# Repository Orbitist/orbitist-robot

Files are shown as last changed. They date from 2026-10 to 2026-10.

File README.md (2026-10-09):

# Orbitist Robot

An open-source, general-purpose farm robot that farmers can build from off-the-shelf, salvaged, and used parts, plus 3D-printed pieces and lightly fabricated metal.

**First job:** autonomously mowing the lawns on our farm (prototype built winter 2026–27).
**Later jobs:** towing small loads (mulch), carrying sensors, and a light arm for weeding and pruning.

## Status

Design, analysis, and simulation, done before buying parts. Start with:
- **[Platform v1 design](docs/design/platform-v1.md)**: what we're building and why
- **[Confidence plan](docs/design/confidence-plan.md)**: what's verified, what isn't, and the tests to run before the main purchase
- **[Simulation](software/sim/README.md)**: plan mowing and run the autopilot in software
- **[Build tutorial](docs/build/README.md)**: step-by-step assembly with purchase links, one step at a time
- **[Form factors from first principles](docs/design/form-factor-exploration.md)**: swarms, gantries, cable robots, animals, solar: what shape of robot a polyculture farm needs, and what it changes for v1

## Repository layout

```
docs/
  concept/     Original concept work (Sept 2026 vineyard robot design report)
  design/      Current design documents (platform-v1.md)
  decisions/   Decision log: what we chose and why
  guides/      How-to guides (RTK base station setup)
  build/       Step-by-step build tutorial with purchase links and a measurements record
hardware/
  bom/         Bills of materials (CSV) and ordering plan
  cad/         Parametric CAD model, renders, cutting DXFs, strength check
  electrical/  Power distribution, e-stop safety chain, wiring, commissioning tests
software/
  ardupilot/       Autopilot parameters + blade-interlock Lua script
  sim/             Coverage planner + ArduPilot SITL acceptance tests
  base-station/    RTK base (u-blox ZED-F9P) configuration script
  estop_receiver/  Fail-safe wireless e-stop firmware (Arduino)
```

## License

Hardware: [CERN-OHL-W-2.0](LICENSES/CERN-OHL-W-2.0.txt) · Software: [Apache-2.0](LICENSES/Apache-2.0.txt) · Docs: [CC BY-SA 4.0](LICENSES/CC-BY-SA-4.0.txt). See [LICENSE.md](LICENSE.md) for what applies where.

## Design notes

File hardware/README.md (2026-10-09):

# Hardware

| Folder | Contents |
|---|---|
| `bom/` | Bills of materials as CSV (one file per platform version) and the [ordering plan](bom/ordering-plan.md) (what to buy when). Prices are rough estimates as of Oct 2026. |
| `cad/` | [Parametric build123d model](cad/README.md) of the frame: STEP, renders, DXF plates, cut list, mass/CG report |
| `electrical/` | [Power distribution, e-stop safety chain, signal wiring, fuses, commissioning tests](electrical/README.md) |

Design rationale lives in [`docs/design/platform-v1.md`](../docs/design/platform-v1.md).

**v1 BOM rough totals (new parts):**
- Core mowing robot (razor deck + solar roof) + RTK base station (phases 0–1c, without optional GPS-yaw): **~$3,400**
- Everything listed, including GPS-yaw, hitch, and phase-2 compute and sensors: **~$4,040**

Analyses that regenerate from the CAD parameters: [strength](cad/exports/strength-report.md), [drive & energy](cad/exports/drive-energy-report.md), [layout & clearances](cad/exports/report.md).

The RTK base (~$280) is a one-time farm asset shared by every future robot. There is no charging dock: the solar roof keeps the robot charged (D28). The biggest savings come from salvaged parts: a hoverboard board instead of VESCs (−$135), a used e-bike pack, and used rigid solar panels.

Licensed under [CERN-OHL-W-2.0](../LICENSES/CERN-OHL-W-2.0.txt).

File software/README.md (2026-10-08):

# Software

| Folder | Contents |
|---|---|
| [`ardupilot/`](ardupilot/README.md) | Rover 4.6 parameter files and the blade-interlock Lua script that run on the flight controller |
| [`sim/`](sim/README.md) | Coverage planner (lawn → missions + fences) and ArduPilot SITL acceptance tests |
| [`base-station/`](base-station/README.md) | RTK base station configuration (u-blox ZED-F9P) |
| [`estop_receiver/`](estop_receiver/README.md) | Fail-safe wireless e-stop firmware (Arduino Nano) |
| `ros2/` | *(phase 2)* Companion-computer workspace on the Pi 5: camera, obstacle detection, dock AprilTag |

Architecture: [`docs/design/platform-v1.md` §6.3](../docs/design/platform-v1.md#63-navigation-and-control).

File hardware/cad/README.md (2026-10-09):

# CAD: platform v1 frame (code-based, build123d)

The robot is modelled in Python with [build123d](https://github.com/gumyr/build123d) (OpenCascade kernel). `params.py` holds every dimension in one place. `build.py` regenerates the STEP files, renders, flat-plate DXFs, cut list, and an engineering report.

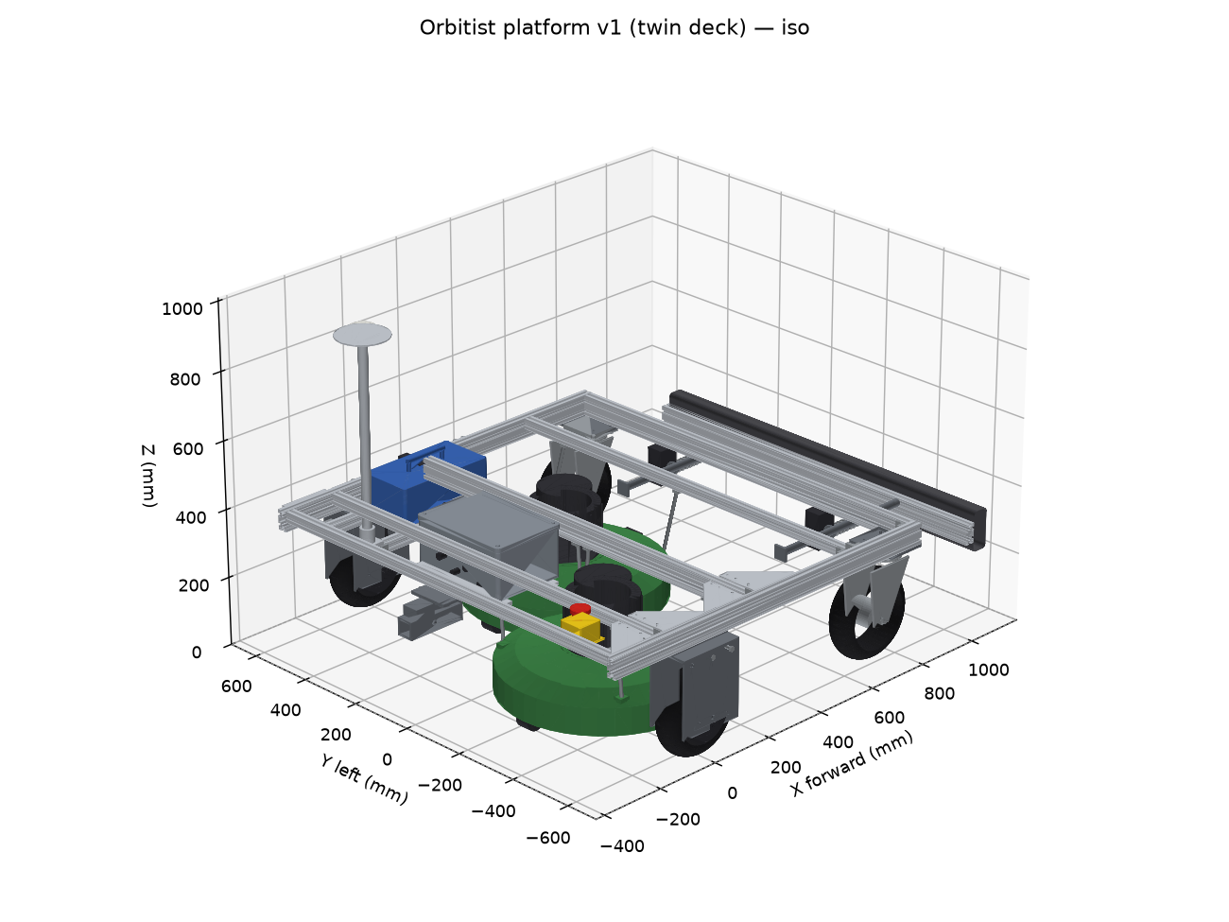
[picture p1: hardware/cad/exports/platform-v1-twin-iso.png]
Twin-deck layout, isometric


## Files

| File | What it is |
|---|---|
| `params.py` | **All dimensions and masses.** Values marked `ESTIMATE` are typical sizes for parts we haven't bought; replace them with measurements. |
| `model.py` | Assembles the parts and re-exports the helpers the analyses use |
| `parts/common.py` | T-slot extrusion profile (30-series, slot 8), hex bolts and nuts, rods, colours by material |
| `parts/plates.py` | **2D outlines of every cut plate** (fork side plate, torque arm, gusset, caster plate). The 3D model extrudes them and the DXFs are exported from them, so they can't drift apart. |
| `parts/frame.py` | Rails and members with real T-slot sections, cast corner brackets, top-face gussets, battery support rails, all bolts |
| `parts/drive.py` | Hub motors (treaded tire, rim, can, side covers, flatted axle), bolt-on forks with saddle tabs, torque arms, axle nuts, motor cables |
| `parts/casters.py` | Plate-mount swivel casters (top plate with bolt pattern, raceway, yoke legs, axle, hub) on the steel corner plates |
| `parts/deck.py` | Ryobi-class deck shells (revolved pan with skirt and rib), blades with lift wings, finned motor housings, anti-scalp rollers, four threaded-rod hangers per deck with drop-in slot blocks |
| `parts/razor_deck.py` | Razor-disc deck: plate cut back to the caster swivel circle, skirt, four disc motors, discs from `razor-disc.dxf`, pivoting blades, rollers, hangers |
| `parts/roof.py` | Solar roof: posts, rails, panels, MPPT, GNSS antenna stub and e-stop on the rear rail |
| `parts/payload.py` | Battery with handle and connector on a lipped tray with strap, IP65 box with lid, glands and mounting feet, GNSS mast with ground plane and antenna, e-stop, 2" hitch receiver with pin, sprung bumper with guide blocks, trip collars and roller microswitches |
| `build.py` | Exports everything to `exports/` and runs clearance checks |
| `strength.py` | Hand-calculation strength check → `exports/strength-report.md` |
| `drive_energy.py` | Hub-motor operating points, heating, and the daily energy budget → `exports/drive-energy-report.md` |
| `exports/platform-v1-{single,twin}.step` | Full assembly. Open in Onshape (*Import*), FreeCAD, Fusion, or any STEP viewer. |
| `exports/*-{iso,top,side,front}.png` | Quick-look renders |
| `exports/platform-v1-detail-*.png` | Close-ups: drive module, front corner (caster + bumper), Ryobi deck hangers, rear, razor deck from below, solar roof |
| `exports/*.dxf` | Flat patterns: drive-fork side plate (6 mm steel ×4), torque arm (5 mm steel ×4), frame gusset (×8), caster plate (×2), razor disc (3 mm aluminium ×4) |
| `exports/strength-report.md` | Load cases, stresses and safety factors for forks, joints, and frame members |
| `exports/cut-list.md` | Extrusion lengths to cut |
| `exports/report.md` | Envelope, mass, CG, axle loads, tongue-weight limit, clearance checks |

## Configurations

- **razor** (v1 baseline, D27/D28): four Ø280 mm razor-blade discs on a 3 mm plate with an HDPE skirt, 1.06 m symmetric cut, plus the solar roof (posts, 30x30 roof frame, two panels, MPPT) carrying the GNSS antenna and e-stop.
- **single**: one Ryobi deck in the twin layout's **rear-right** slot (weekly-capable cutting, needs the dock), no roof.
- **twin**: v1.5, two decks **staggered** (rear-right, front-left) so their cuts overlap by 50 mm. Two decks side by side would leave an uncut strip, because the deck housing is wider than the blade. The frame is the same for both.

## Regenerate

```bash
cd hardware/cad
uv venv --python 3.12 .venv
uv pip install --python .venv/bin/python -r requirements.txt
.venv/bin/python build.py
.venv/bin/python strength.py
.venv/bin/python drive_energy.py
```

`build.py --details` regenerates only the close-up renders (fast) while adjusting views. A full build takes about a minute, most of it in clearance checks and renders.

Commit the regenerated `exports/` together with the parameter change, so the repo stays readable without Python.

## What this model is (and isn't)

- **Detailed layout model (v1).** Every structural part is modelled the way it would be built: real T-slot sections, bolted joints with brackets and gussets, plates from the same outlines as the DXFs, fasteners at every joint. Purchased parts (hub motors, casters, the Ryobi deck, battery, enclosure) are modelled from typical catalog dimensions and will be replaced by measured ones (below). The STEP has ~350 solids and opens in Onshape or FreeCAD.
- **Clearance checks** run on the full model: decks (shell, blade, motor, rollers) against the frame, brackets, forks, wheels and casters; caster swivel sweep against the decks and bumper parts; hangers against everything they shouldn't touch; payload against the deck motors; bumper travel against the caster sweep. The detailed model caught one clash the block model missed: the right hub motor's cable exit ran into deck 1's skirt, which is only ~18 mm from the axle end. The cable now turns up at the axle.
- **Strength:** `strength.py` hand-checks the forks, joints, and members ([report](exports/strength-report.md)). It led to the torque arms, saddle-mounted forks, gussets, and the 30x60 member at x = 215. It's not FEA; the frame is simple enough that beam and plate checks catch the real risks.
- **Not modelled yet:** wiring beyond the motor cables, the belly pan, the VESCs inside the enclosure, the deck's blade-brake and switch wiring, and the charging-dock contacts (phase 2).

## Measure when parts arrive, then update `params.py`

1. Hub motor: tire OD and width, **dropout spacing** (shoulder to shoulder), **axle flats width**, axle length past each shoulder
2. Caster: wheel OD and width, trail, overall height from ground to the mounting plate
3. Ryobi deck (handle and wheels removed): housing outline, motor housing diameter and height, cutting height range, mass
4. Battery and enclosure dimensions

Licensed under [CERN-OHL-W-2.0](../../LICENSES/CERN-OHL-W-2.0.txt); the code in this folder is also available under [Apache-2.0](../../LICENSES/Apache-2.0.txt).

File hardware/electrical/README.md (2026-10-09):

# Electrical design: platform v1

*Status: design for review before purchasing. Part numbers are examples; any part meeting the listed ratings works.*

The design follows four rules:

1. **Every fault fails toward "stopped".** The e-stop loop is normally-closed and in series, and every element in it must be actively *held* closed. A broken wire, a dead radio, or a crashed computer all stop the robot.
2. **Stop, then disconnect.** Cutting power to the motor controllers instantly makes hub motors *coast*. On grass at 1 m/s that's ~0.5 m of rolling, so the e-stop first commands **active braking** and then removes drive power about 1 s later. This is a "Category 1" stop in machine-safety terms.
3. **The safety chain doesn't depend on software.** ArduPilot also disarms on an e-stop, but the hardware path brakes and disconnects even if the autopilot is frozen or commanding full speed.
4. **The blade has its own cut-off**, which drops instantly with the e-stop loop no matter what the autopilot commands.

---

## 1. Power distribution

```mermaid
flowchart LR
    BAT["36 V battery<br/>10S Li-ion / 12S LFP, 20 Ah<br/>BMS ≥ 30 A"] --> F1["F1 main fuse 40 A<br/>(58 V DC rated, MRBF)"]
    F1 --> SW1["SW1 battery disconnect<br/>(≥ 48 V DC rated)"]
    SW1 --> PM["Power module<br/>V + I sense → autopilot"]
    PM --> K1["K1 main contactor<br/>12 V coil, ≥ 60 V DC, ≥ 50 A"]
    PM --> K2R["K2 precharge relay + R1 47 Ω 10 W<br/>(in parallel with K1)"]
    K1 --> BUS["Motor bus 36 V"]
    K2R --> BUS
    BUS --> F2["F2 25 A"] --> VL["VESC left"] --> ML(("Hub motor L"))
    BUS --> F3["F3 25 A"] --> VR["VESC right"] --> MR(("Hub motor R"))
    PM --> F4["F4 5 A"] --> DC12["DC-DC 36→12 V 10 A"]
    PM --> F8["F8 2 A"] --> DC5["DC-DC 36→5 V 5 A"]
    PM -.->|5.2 V| FC["Flight controller"]
    DC12 --> R12["12 V rail (always on):<br/>e-stop loop, contactor coil, timers,<br/>payload, lights"]
    DC5 --> R5["5 V rail (always on):<br/>e-stop receiver, RTCM radio,<br/>relay modules, Pi (phase 2: own 5 V 5 A)"]
```

- **Electronics stay powered during an e-stop** (they're fed before K1), so the autopilot keeps logging, GPS keeps its fix, and the robot can report what happened. SW1 is the only thing that turns everything off.
- **Precharge:** VESCs have large input capacitors. Closing K1 onto empty capacitors arcs and eventually welds the contactor. K2 + R1 charge the capacitors first (τ ≈ 47 Ω × ~3000 µF ≈ 0.15 s), and K1 closes 1.5 s later.
- **Blade power (razor deck, D27):** the four disc drivers take 36 V from the motor bus through F6 (15 A) and are switched together by K5's contacts on their enable lines, so one relay drops all four discs. (The earlier Ryobi-deck plan, with the deck on its own battery, is kept in §6 for the `twin` configuration.)
- **Solar (D28):** the MPPT charge controller's output connects to the battery side of F1 through its own 15 A fuse, so it charges whether or not SW1 is on; its panel input comes down from the roof through a gland.

## 2. Safety chain (e-stop loop)

```mermaid
flowchart LR
    V12["+12 V"] --> F5["F5 2 A"] --> S1["S1 mushroom<br/>e-stop (NC)"] --> S2["S2 bumper<br/>switch L (NC)"] --> S3["S3 bumper<br/>switch R (NC)"] --> K3["K3 wireless e-stop<br/>relay (held closed<br/>by receiver)"] --> SAFE(["SAFE 12 V"])
    SAFE --> K4["K4 signal relay (DPDT)<br/>passes VESC L/R PWM"]
    SAFE --> K2C["K2 precharge relay coil"]
    SAFE --> T1["T1 ON-delay 1.5 s"] --> T2["T2 OFF-delay 1.0 s<br/>(powered from always-on 12 V)"] --> K1C["K1 contactor coil"]
    SAFE --> K5C["K5 blade relay coil<br/>(switched by autopilot)"]
    SAFE --> OPTO["Optocoupler → autopilot GPIO<br/>'ESTOP_OK'"]
```

**What happens when the loop opens** (button pressed, bumper hit, transmitter off or out of range, wire broken):

| Time | Event | Independent of software? |
|---|---|---|
| 0 ms | **Blade relay K5 drops**, cutting the blade start circuit; the mower's own brake stops the blade (< 3 s) | ✅ |
| 0 ms | **K4 opens the PWM signal lines** to both VESCs | ✅ |
| ~100 ms | VESCs detect signal timeout and apply **timeout brake current**, braking the robot to a stop | ✅ (VESC firmware setting) |
| ~0–100 ms | Autopilot sees ESTOP_OK go low, disarms, sets the blade relay output off, logs the event | software, belt-and-braces |
| 1.0 s | T2 releases → **K1 opens, removing drive power** (and K2 has already dropped) | ✅ |

**What happens when the loop closes again:**
1. K2 precharges the VESC capacitors.
2. After 1.5 s, T1 → T2 → K1 closes the main contactor.
3. K4 reconnects the PWM lines, but the **robot does not move**: ArduPilot is disarmed and outputs no pulses (`MOT_SAFE_DISARM = 1`), so the VESCs keep braking. Moving again needs a deliberate re-arm on the transmitter's arm switch, and the blade needs a mission command.

**Stopping distance** (bumper design: see [`strength-report.md`](../cad/exports/strength-report.md#bumper-stopping-distance)): braking at ~3 m/s² after ~0.12 s of latency. That's why **v1 mows at 0.6 m/s**.

## 3. Signal wiring

```mermaid
flowchart LR
    subgraph FC["Flight controller (Pixhawk 6C class)"]
      S1o["MAIN/AUX 1"]
      S3o["MAIN/AUX 3"]
      RLY["AUX n (relay out)"]
      GPIO["AUX m (GPIO in)"]
      GPS1["GPS1"]
      TEL1["TELEM1"]
      RCIN["RC IN / serial"]
    end
    S1o --> K4a["K4 contact A"] --> VLs["VESC L PPM in"]
    S3o --> K4b["K4 contact B"] --> VRs["VESC R PPM in"]
    RLY --> K5M["Opto relay module IN<br/>(K5 coil from SAFE 12 V)"] --> RYOBI["Ryobi start circuit<br/>(see §6)"]
    OPTO2["Optocoupler (SAFE 12 V)"] --> GPIO
    GPS1 --- F9P["Rover ZED-F9P (UART1)"]
    RADIO["RTCM radio (from base)"] --> F9P2["Rover ZED-F9P UART2"]
    TEL1 --- SIK["Telemetry radio ↔ laptop"]
    RCIN --- ELRS1["ELRS receiver #1<br/>(driving, arm switch)"]
    ELRS2["ELRS PWM receiver #2"] --> NANO["E-stop receiver<br/>(software/estop_receiver)"] --> K3c["K3 relay (in e-stop loop)"]
```

- With K4 open, each VESC's PPM input must be **pulled to ground** (10 kΩ at the VESC end) so it sees "no signal" rather than noise.
- Run PWM and sensor wires as twisted pairs with their ground, away from motor phase wires.
- **One ground point:** the battery negative at the power module. Signal grounds follow their signals. Don't create a second path through the frame.

## 4. Fuses and wire

All fuses and fuse holders on the 36 V side must be **rated ≥ 58 V DC**. Ordinary automotive blade fuses are rated 32 V and may not interrupt a 42 V DC fault.

| Circuit | Fuse | Wire (silicone, chassis wiring) | Notes |
|---|---|---|---|
| Battery → SW1 → power module → K1 | F1 40 A (MRBF or Class T at the battery) | 10 AWG | As short as possible; F1 within 15 cm of the battery |
| Motor bus → each VESC | F2/F3 25 A (58 V ATO/MINI) | 12 AWG | Battery current limit per VESC is set to 14 A (§5) |
| Precharge K2 + R1 | inherent (R1 limits to < 1 A) | 18 AWG | R1: 47 Ω, 10 W, wirewound |
| DC-DC 12 V input | F4 5 A | 16–18 AWG | |
| DC-DC 5 V input | F8 2 A | 18 AWG | |
| E-stop loop (12 V) | F5 2 A | 20 AWG | Contactor coil ~0.3–0.5 A |
| Signals | — | 22–26 AWG twisted | |

Crimp, don't solder, anything that vibrates (use ferrules on screw terminals) and strain-relieve at the enclosure glands.

## 5. Settings that are part of the safety design

These live in configuration rather than wiring, but the design depends on them. Record them in `software/ardupilot/` and in the VESC config backups.

**VESC (each controller, VESC Tool):**

| Setting | Value | Why |
|---|---|---|
| Sensor mode | Hall sensors (FOC) | Smooth low-speed torque (design doc §5) |
| Battery current max | 14 A | Two VESCs stay under the 30 A BMS limit |
| Motor current max | ~50 A | ≈ 28 N·m with a typical torque constant of ~0.57 N·m/A. Keeps torque under the 40 N·m the forks and torque arms were checked for. Re-compute from the measured motor constant after VESC motor detection. |
| Motor current max brake | 30 A | Braking torque |
| App: PPM, **control type "PID speed"**, max ERPM ≈ 2 m/s wheel speed | — | Throttle maps linearly to wheel speed, so 0.6 m/s is 30 % throttle instead of ~7 % duty. Gives finer low-speed control and an easier ArduPilot speed tune (`CRUISE_THROTTLE 30`). |
| App: PPM, **timeout 100 ms**, **timeout brake current 20 A** | — | This is what stops the robot when K4 cuts the signal or the autopilot dies |
| Battery cutoff start/end | Set for the pack chemistry | Protects the battery before the BMS has to |

**ArduPilot (Rover):** skid-steer outputs `SERVO1_FUNCTION = 73`, `SERVO3_FUNCTION = 74`; `MOT_SAFE_DISARM = 1` (no pulses when disarmed); arm with a **switch**, never stick-arming; RC and GCS failsafe → Hold; battery failsafe from the power module; geofence → Hold. A Lua script watches the ESTOP_OK input and disarms. The full parameter file comes with the autopilot setup.

## 6. Open item: Ryobi blade control (bench test)

How the robot switches the blade depends on the specific mower:

1. Open the handle wiring. Find the **bail switch** (the lever you hold) and the **start button**.
2. With a multimeter, measure the current through each while the mower runs (on a bench, blade removed or safely guarded).
   - **Low current (< 1 A):** these are signal inputs to the mower's brushless controller. K5 can be a small relay replacing the bail switch, plus a second relay or the same relay to "press" start (a ~0.5 s pulse from the autopilot, held by the bail relay).
   - **High current:** the bail switch carries motor power. K5 must be a DC contactor rated ≥ 60 V DC at the motor current.
3. Confirm that opening the bail circuit stops the blade within 3 s (blade brake).

Record the results in this file and update the K5 entry.

## 7. Parts list (electrical)

| Ref | Part | Rating / notes |
|---|---|---|
| F1 | Terminal-mount fuse (Blue Sea MRBF class) + holder | 40 A, 58 V DC |
| SW1 | Battery disconnect switch (Blue Sea m-Series class) | ≥ 48 V DC, ≥ 50 A |
| PM | Analog power module | ≥ 12S input, ≥ 60 A; supplies the flight controller |
| K1 | DC contactor, 12 V coil | ≥ 60 V DC, ≥ 50 A continuous (e.g. Albright SW60 / TE LEV100 class) |
| K2, R1 | 12 V automotive relay + 47 Ω 10 W resistor | Precharge |
| T1 | 12 V on-delay timer relay module | Adjustable, set 1.5 s |
| T2 | 12 V off-delay timer relay module | Trigger input + separate supply, set 1.0 s |
| K3 | 5 V relay module, active-HIGH | Driven by the e-stop receiver |
| K4 | 12 V DPDT signal relay | Gold-flashed contacts for low-level signals |
| K5 | 12 V-coil relay with opto-isolated 3.3 V input | Or a DC contactor; depends on the §6 bench test |
| S1 | 22 mm mushroom e-stop, twist-release, **NC** contact block | Mounted at the rear top, reachable from behind the robot |
| S2, S3 | Roller-lever microswitches, **NC** used | IP67 if available |
| — | Optocoupler module (12 V in → 3.3 V out) | ESTOP_OK to the autopilot |
| — | 2× DC-DC converters | 36→12 V 10 A, 36→5 V 5 A; input ≥ 60 V |
| — | 58 V fuse block + fuses | F2–F8 |
| — | E-stop receiver | Arduino Nano + ELRS PWM receiver ([software/estop_receiver](../../software/estop_receiver/README.md)) |

## 8. Commissioning tests

Do these in order, with the **drive wheels off the ground** and **no blade fitted** until step 6.

1. **Polarity and fuses:** with SW1 off, check every fuse is fitted. Measure the main bus with a meter before the first switch-on, using a current-limited bench supply if possible.
2. **Precharge:** loop closed → bus voltage rises within ~0.5 s → contactor clicks at ~1.5 s with no spark or arc sound.
3. **Each loop element** (S1, S2, S3, transmitter off, RUN switch down, a loop wire unplugged) must each:
   - drop the blade relay immediately,
   - make the wheels brake within ~0.1 s (spin them by hand first: they should resist),
   - open the contactor after ~1 s,
   - make the autopilot log "ESTOP" and disarm.
4. **No restart:** re-close the loop → the robot stays disarmed and the wheels stay braked until re-armed.
5. **Autopilot crash:** while driving with the wheels lifted, unplug the flight controller's power → the VESCs brake within 0.1 s from the signal timeout.
6. **Blade:** with the deck fitted and guarded, run the blade and hit the e-stop → the blade stops in < 3 s.
7. **On the ground:** at 0.6 m/s, push the bumper with a padded board → the robot stops within the bumper's travel.

Repeat steps 3 and 6 at the start of every mowing season and after any wiring change.

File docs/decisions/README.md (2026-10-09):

# Decision log

A short record of design decisions, so future contributors can see *why* things are the way they are. Add a row when a decision is made or revisited. Write a longer note only when a row isn't enough.

| # | Date | Decision | Status | Rationale / link |
|---|---|---|---|---|
| D1 | 2026-10-08 | Build **one robot first**; peer-to-peer docking becomes a later research track | Proposed | Mowing doesn't need a pair; the latch was the top risk. [platform-v1 §2](../design/platform-v1.md#2-what-changes-from-the-vineyard-concept-and-why) |
| D2 | 2026-10-08 | **Zero-turn layout** (2 rear hub motors + 2 front casters) for v1; frame accepts swappable drive modules (wheelchair, 4WD) | Proposed | Turf-friendly pivot turns; proven mower geometry. [§3](../design/platform-v1.md#3-chassis-options-considered) |
| D3 | 2026-10-08 | **ArduPilot Rover** on a flight controller for low-level control and GPS navigation; Pi 5 + ROS 2 added as a companion in phase 2 | Proposed | Mature skid-steer, RTK, missions, failsafes; existing community mower builds. [§6.3](../design/platform-v1.md#63-navigation-and-control) |
| D4 | 2026-10-08 | **RTK GNSS (u-blox ZED-F9P) in phase 1** | Proposed | Coverage mowing needs cm-level repeatability |
| D5 | 2026-10-08 | **VESC-class FOC controllers** by default; hoverboard + EFeru FOC as budget option | Proposed | Direct RC-PWM/CAN from ArduPilot; Hall-sensored low-speed torque |
| D6 | 2026-10-08 | **Mower is a belly-mount module**; v1 uses a salvaged 40 V-max cordless mower deck on its own battery | Proposed | Includes blade brake and height adjust; isolates blade power. [§6.2](../design/platform-v1.md#62-mower-module) |
| D7 | 2026-10-08 | Haul loads by **towing a cart from a rear hitch** rather than carrying them on deck | Proposed | Cart's wheels carry the load; tongue weight adds traction |
| D8 | 2026-10-08 | Battery swap first, then a **fixed AprilTag charging dock** in phase 2 (replaces peer-to-peer charging for lawn use) | Proposed | Simpler; ArduPilot Dock mode exists |
| D10 | 2026-10-08 | Operating model for ~3 acres: **mow in daily zones from a charging dock**; dock is the first item in phase 2 | Proposed | One 21" deck needs ~12.5 h per full pass at 0.6 m/s. [platform-v1 §5](../design/platform-v1.md#5-back-of-envelope-sizing) |
| D11 | 2026-10-08 | **Own RTK base station** (ZED-F9P, position fixed with NOAA OPUS), 915 MHz radio link to the robot; NTRIP caster later | Proposed | No known correction service nearby; one base serves the whole farm |
| D12 | 2026-10-08 | Mower module from a **second used Ryobi mower** sharing the farm's existing batteries and charger | Proposed | Keeps the daily mower in service; reuses the battery ecosystem. Pending model number. |
| D13 | 2026-10-08 | **Code-based CAD (build123d) in `hardware/cad/` is the source of truth**; Onshape/FreeCAD for viewing STEP exports and quick hand-sketched parts (revised same day; originally Onshape) | Accepted | Parametric, diffable in git, regenerates DXFs/cut list/strength check, editable by Claude. [hardware/cad](../../hardware/cad/README.md) |
| D14 | 2026-10-08 | **Frame built for twin decks from day one** (~1.3–1.4 m wide); v1 runs one centered deck | Proposed | 3+ acres, flat, 8 ft paths; widening later would mean rebuilding the frame. [platform-v1 §4](../design/platform-v1.md#4-v1-layout-top-view) |
| D15 | 2026-10-08 | **Licenses:** CERN-OHL-W-2.0 (hardware), Apache-2.0 (software), CC BY-SA 4.0 (docs) | Accepted | Anyone can build and sell; changes to our hardware design are shared back; third-party modules can stay closed; software matches ROS 2. [LICENSE.md](../../LICENSE.md) |
| D16 | 2026-10-08 | From the strength check: **torque arms required**, **saddle-mounted drive forks**, **gussets** at the drive-adjacent joints, **30x60 cross member at x = 215**, **no towing** until an A-frame drawbar is added | Accepted | [strength-report.md](../../hardware/cad/exports/strength-report.md) |
| D17 | 2026-10-08 | **Plate-mount 10" pneumatic swivel casters** on 8 mm steel corner plates (instead of zero-turn mower casters); frame raised to 320 mm; front cross member 30x60 | Accepted | Bolt-on, no welded spindle housing, cheap and swappable. Upgrade to mower casters if shimmy is a problem. |
| D18 | 2026-10-08 | **Category 1 e-stop** (signal cut → VESC brake → contactor opens after 1 s), hardware-only path; **fail-safe wireless e-stop** via microcontroller watchdog; **v1 mowing speed 0.6 m/s** to stay within bumper stopping distance | Accepted | Hub motors coast if power is cut instantly; the bumper only protects ≤ 0.61 m/s. [electrical](../../hardware/electrical/README.md), [strength-report](../../hardware/cad/exports/strength-report.md#bumper-stopping-distance) |
| D19 | 2026-10-08 | Base position from a **24 h log processed by CSRS-PPP**; configure the F9P with our own script (no u-center, so it works on Mac and Pi) | Accepted | [rtk-base-station guide](../guides/rtk-base-station.md) |
| D20 | 2026-10-08 | **v1 deck in the rear-right slot**, not centred | Accepted | Cuts within ~19 cm of obstacles on the right (vs ~43 cm); planner laps put the deck on the boundary; the twin upgrade only adds a deck |
| D21 | 2026-10-08 | **Simulation gate:** every parameter or Lua change must pass `software/sim/run_sitl.py` before it goes on the robot | Accepted | SITL found eight real problems before hardware ([sim README](../../software/sim/README.md)) |
| D22 | 2026-10-08 | Autopilot settings from SITL: `AVOID_ENABLE 2` (no fence avoidance), `WP_RADIUS 0.2`, 15 cm pass overlap, 0.25 m extra obstacle clearance, **pause on RTK loss** (Lua) | Accepted | Each fixes a failure seen in simulation |
| D23 | 2026-10-08 | Own **coverage planner** (perimeter laps + stripes + visibility-graph routing, fences within 80 points) instead of Mission Planner's grid tool | Accepted | Knows the offset deck, the body width, and obstacle clearance; one mission + fence per zone |
| D24 | 2026-10-08 | **De-risk before buying** (T1 Ryobi blade power, T2 RTK survey, T3 one-motor bench test, T4 caster); **battery choice waits for T1** | Accepted | Blade power and motor heating are the two biggest unknowns ([confidence plan](../design/confidence-plan.md)) |
| D25 | 2026-10-08 | VESC PPM in **PID speed** mode (throttle ∝ wheel speed, ~2 m/s full scale) | Proposed | 0.6 m/s = 30 % throttle instead of ~7 % duty; finer low-speed control |
| D26 | 2026-10-08 | The platform is a *system*: v1 carrier for mass + mowing, a 1-D bed gantry or cable robot for polyculture beds (v2), drone + fixed cameras for sensing, animals for margins | Accepted 2026-10-09 | [form-factor-exploration](../design/form-factor-exploration.md); user confirmed daily mowing, solar, animals and a test plot are all welcome |
| D27 | 2026-10-09 | **v1 cutting system is a razor-disc deck** (4 × Ø280 mm discs with pivoting razor blades, ~10–20 W each) for daily increment cutting, replacing the Ryobi deck as the baseline. The farm's existing Ryobi (and the Swisher) are the catch-up mowers for tall growth and spring. | Accepted | 3–10× less cutting energy; lighter, safer deck; symmetric 1.06 m cut. [drive-energy report](../../hardware/cad/exports/drive-energy-report.md) |
| D28 | 2026-10-09 | **Solar roof** (2 × ~110 W semi-flexible panels on a 30x30 roof frame) with an MPPT charger; **36 V 10–15 Ah pack; no charging dock.** GNSS antenna and e-stop move onto the roof's rear rail. | Accepted | ~500–740 Wh/day supply vs ~250 Wh/day typical need; removes phase 2's hardest item |
| D29 | 2026-10-09 | **Sheep with a virtual fence** are the planned mower for orchard floors and margins; the robot mows open lawns | Proposed | Zero-energy mowing plus fertility; user already considering sheep |
| D30 | 2026-10-09 | **v2 is a 1-D bed gantry or cable robot** on a dedicated test plot, sharing v1's electronics; an arm stays on the long-term roadmap | Proposed | Polyculture beds need place/protect work, not a bigger carrier |
| D31 | 2026-10-09 | **Evaluate a ground-driven reel gang** (3 used push reel mowers, belly-mounted, floating on their own wheels) as an alternative to the razor discs; decide from the T1/T1b field test | Open | Shear cut needs no blade electronics or interlock and is inherently stopped when the robot is; but sticks and stalky weeds jam reels, and the drag loads the drive wheels. [step 1 T1b](../build/step-01-de-risk.md) |
| D9 | 2026-10-08 | Correction: "36 V" means **10S Li-ion or 12S LiFePO4** (concept report said 10S LiFePO4, which is only 32 V) | Accepted | Cell chemistry math |

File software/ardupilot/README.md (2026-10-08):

# ArduPilot configuration

| Path | What |
|---|---|
| `params/orbitist-v1.param` | Baseline Rover 4.6 parameters for the real robot: frame, speeds, arming, failsafes, fence, blade relay, scripting. Values marked TUNE are set during commissioning. |
| `params/sitl-overlay.param` | Simulation-only overrides (loaded by `software/sim`). **Never load on the robot.** |
| `scripts/blade_interlock.lua` | Blade interlock + GPS pause/resume + e-stop disarm. Copy to the flight controller's SD card under `APM/scripts/`. |

## Blade control

Missions don't switch the blade relay directly. They send `MAV_CMD_DO_SEND_SCRIPT_MESSAGE` (id 1, param2 = 1 on / 0 off), and the Lua script turns relay 1 (K5) on only while **all** of these hold:

armed · AUTO mode · GPS fix ≥ `BLD_MIN_FIX` (RTK fixed) · no fence breach · tilt < 25° · e-stop loop OK · blade requested

The script also:
- disarms if the e-stop loop opens (the hardware e-stop acts independently: see `hardware/electrical`);
- pauses the mission (Hold) if the RTK fix is lost for 2 s, and resumes once it's been back for 3 s;
- forces the blade off if the script itself errors.

Its parameters (`BLD_*`) appear after the first boot with the script installed. Set `BLD_ESTOP_SRC = 1` and `BLD_ESTOP_PIN` to the GPIO wired to the ESTOP_OK optocoupler. With the pin unset, the script treats the e-stop as tripped (fail safe).

## Installing on the flight controller

1. Flash ArduPilot **Rover 4.6.x** (the version the simulation uses).
2. Mission Planner → Config → Full Parameter List → **Load from file** → `orbitist-v1.param` → Write → reboot.
3. Copy `scripts/blade_interlock.lua` to the SD card at `APM/scripts/`, reboot, and check for "Blade interlock loaded" in Messages.
4. Commission in the order given in `hardware/electrical/README.md` §8, then tune steering and speed per the [ArduPilot Rover tuning guide](https://ardupilot.org/rover/docs/rover-tuning-process.html).
5. Commit any tuned values back to `orbitist-v1.param`.

Every behaviour above is exercised in simulation by `software/sim/run_sitl.py`.

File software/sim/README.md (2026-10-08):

# Simulation: plan and test mowing before the robot exists

Two tools, both using the robot's real geometry (`hardware/cad/params.py`) and its real autopilot configuration (`software/ardupilot/`):

| Tool | What it does |
|---|---|
| `coverage.py` | **Mowing planner.** Turns a lawn file into ArduPilot missions (one per zone, i.e. one day's job), geofences, a coverage map, and a time estimate. |
| `run_sitl.py` | **Acceptance tests.** Boots ArduPilot Rover 4.6.3 in software-in-the-loop (SITL) with our parameters and the blade-interlock Lua script, flies the planned mission, and injects faults. |

## Setup (once, ~10 min)

```bash
cd software/sim
./setup.sh
```

This creates a Python 3.12 environment and downloads and compiles ArduPilot SITL into `ardupilot/` (git-ignored).

## Plan mowing

```bash
.venv/bin/python coverage.py lawns/sample-farm.json                 # single deck
.venv/bin/python coverage.py lawns/sample-farm.json --config twin   # twin decks
```

Output goes to `plans/<lawn>-<config>/`:
- `<zone>.waypoints`: load in Mission Planner.
- `<zone>.plan`: load in QGroundControl. Includes the fence.
- `<zone>-fence.json`: the fence on its own.
- `<zone>.png`: map of the plan. Red marks area the robot can't reach.
- `report.md`: time and coverage per zone.

**The pattern:** the deck sits on the robot's right, so the robot first runs two laps with the deck facing the boundary: counter-clockwise around the lawn, clockwise around trees and beds. It then mows straight stripes at whichever angle needs the fewest turns. At each stripe end the offset deck makes the robot pivot 180° almost in place.

**Lawn files** (`lawns/*.json`) are in metres east/north of an origin. `sample-farm.json` is an invented ~3-acre layout. Replace it with the real lawns once the RTK rover has walked the boundaries; the planner accepts the same format.

## Run the acceptance tests

```bash
.venv/bin/python run_sitl.py                         # all scenarios, small test plot (~3 min)
.venv/bin/python run_sitl.py mission --lawn lawns/sample-farm.json --zone east --speedup 40
```

| Scenario | Pass criteria |
|---|---|
| `mission` | completes; tracking p95 ≤ 0.15 m while mowing; actual cut ≥ planned − 2 %; blade only on while armed in AUTO |
| `rc_loss` | transmitter lost → Hold and blade off within 2.5 s |
| `estop` | e-stop loop opens → disarmed and blade off within 0.5 s |
| `restart` | e-stop released → stays disarmed and still |
| `gps_loss` | GPS lost → blade off within 1 s, paused within 3 s, < 2 m travelled; resumes when the fix returns |
| `fence` | commanded outside the fence → stays within 1 m of it |

Results: [`results/test-plot.md`](results/test-plot.md). Per-run logs, ArduPilot `.BIN` logs, and track plots go in `runs/` (git-ignored).

## What simulation found (and what changed because of it)

| Found in SITL | Change |
|---|---|
| ArduPilot's **fence avoidance** keeps the robot 2 m (`AVOID_MARGIN`) from the fence, stalling the perimeter laps | `AVOID_ENABLE = 2` (proximity only); the fence still stops the robot on a breach |
| **Corner-cutting** with `WP_RADIUS 0.3` took the robot into the fence around a tree | Laps keep an extra 0.25 m from trees and beds; the fence sits where the body would touch; `WP_RADIUS 0.2` |
| **Waypoints a few cm apart** (stripe-end hops) made the robot pivot back and forth for minutes | Planner merges legs < 0.3 m into one pivot point |
| With ±0.14 m tracking, a 7.5 cm overlap left uncut strips (−5 % coverage) | Overlap 0.15 m (revisit with real tracking) |
| After **losing GPS**, the robot dead-reckoned ~8 m before ArduPilot's failsafe | Lua pauses (Hold) after 2 s without an RTK fix and resumes when it's back |
| A full-size zone's fence (119 points) exceeded ArduPilot's **84-point fence store** | Conservative fence simplification within an 80-point budget; `BRD_SD_FENCE` on hardware |
| Real pivot turns cost ~3 s more each than estimated | Planner time model calibrated (`PIVOT_OVERHEAD_S = 5`) |
| SITL reads "no PWM" as full reverse | SITL-only `MOT_SAFE_DISARM 0` (the real VESCs brake on missing pulses) |

## Limits of this simulation

- **Vehicle dynamics are generic.** ArduPilot's `rover-skid` model is a small, fast hobby rover (4 m/s, very high acceleration), not a 65 kg robot on grass. It validates mission logic, safety behaviour, failsafes, coverage geometry, and the planner, but **not** tuning, traction, or braking distances. Steering tuning (`ATC_*`, `PSC_*`) happens on the real robot; the SITL overlay's tuning is model-specific.
- **GPS is idealised:** RTK fixed everywhere with 2 cm noise. Tree-canopy dropouts are tested only as total GPS loss (`gps_loss`).
- **No grass, no blade load, no battery sag.**

Field tests in phase 1b/1c (see `docs/design/confidence-plan.md`) cover what the simulator can't.

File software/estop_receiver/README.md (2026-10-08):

# Wireless e-stop receiver

A $5 microcontroller that turns a dedicated RC receiver channel into a **fail-safe** wireless e-stop. The relay closes only while a valid "RUN" signal keeps arriving. Transmitter off, out of range, a broken wire, the switch flipped down, or the firmware hanging all open the e-stop loop.

Why not a cheap RC relay switch? Most of them **hold their last state on signal loss**, which is the opposite of fail-safe.

## Hardware

| Part | Notes |
|---|---|
| Arduino Nano or Pro Mini (5 V, ATmega328P) | Flash with the current (Optiboot) bootloader. The old Nano bootloader can reset-loop with the watchdog, which still fails safe (relay off) but won't run. |
| ELRS **PWM** receiver (e.g. RadioMaster ER-series) | Dedicated to the e-stop, bound to the same transmitter. **Failsafe = "No Pulses".** |
| 1-channel relay module, 5 V coil, active-HIGH input | Contacts in series with the NC e-stop loop ([electrical design](../../hardware/electrical/README.md)) |

Wiring: receiver channel signal → **D2**; **D7** → relay module IN; 5 V and GND from the robot's 5 V rail to the Nano, receiver, and relay module.

Map a **2-position switch** on the transmitter to that channel: up (~2000 µs) = RUN, down = STOP.

## Build

```bash
arduino-cli compile --fqbn arduino:avr:nano:cpu=atmega328 software/estop_receiver
arduino-cli upload  --fqbn arduino:avr:nano:cpu=atmega328 -p /dev/cu.usbserial-XXXX software/estop_receiver
```

## Acceptance test (do it before every mowing season, and monthly)

Each test must drop the relay (you'll hear it click and see the LED blink):

1. Flip the RUN switch down → relay drops within 0.1 s.
2. Turn the transmitter off → relay drops (time how long it takes; should be ≤ 1 s).
3. Walk out of range (or shield the transmitter in a metal box) → relay drops.
4. Unplug the receiver signal wire → relay drops.
5. Power-cycle the Nano with the switch in RUN → relay stays off for ~0.2 s, then closes.

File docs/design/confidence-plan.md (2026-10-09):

# Confidence plan: what's verified, what isn't, and how we close the gaps before buying

*Status 2026-10-09 (revised for the razor deck and solar roof, D27/D28). Companion to [platform-v1.md](platform-v1.md). Update the status column as tests complete.*

The aim: spend the big money (motors, battery, frame, electronics ≈ $1,500) only after the riskiest assumptions are measured. Most risks can be retired with **about $350 of parts we need anyway**.

## 1. Where the design stands

| Area | How it was checked | Confidence | Evidence |
|---|---|---|---|
| Layout, clearances, weight distribution | Parametric CAD with automated clearance checks | ✅ High for geometry; masses are estimates | [`report.md`](../../hardware/cad/exports/report.md) |
| Frame and bracket strength | Hand calculations, 2.5 g bumps, side skid, motor torque | ✅ High, given catalog extrusion properties | [`strength-report.md`](../../hardware/cad/exports/strength-report.md) |
| Bumper stopping distance → 0.6 m/s mowing speed | Kinematics with an assumed 3 m/s² braking | 🟡 Medium: braking rate must be measured | strength report §bumper |
| Autopilot configuration, failsafes, blade interlock | **ArduPilot SITL**: 13/13 acceptance checks (mission, RC loss, e-stop, restart, GPS loss, fence) | ✅ High for logic; vehicle dynamics are generic | [`results/test-plot.md`](../../software/sim/results/test-plot.md) |
| Coverage pattern and mowing time | Planner + SITL. Full-size sample zone with the Ryobi deck: mission completed, 97.5 % cut vs 98.0 % planned, 6.13 h vs 6.1 h predicted. Razor deck (1.06 m cut): 13/13 checks on the test plot, 93.7 % cut vs 94.1 % planned; 3 acres ≈ **7.7 h/week** | ✅ High for the sample layout; the real lawns aren't mapped yet | [`results/sample-farm.md`](../../software/sim/results/sample-farm.md), [`plans/`](../../software/sim/plans) |
| Hub motors at mowing speed (45 rpm) | Operating-point model with uncertainty ranges | 🟡 OK in the typical case; **worst case overheats** | [`drive-energy-report.md`](../../hardware/cad/exports/drive-energy-report.md) |
| Daily energy, battery size, solar balance | Energy model from coverage time × power, solar yield from panel rating × sun-hours | 🟡 Razor-disc power (10–20 W each) and panel yield are typical values, not measured; typical day has ~3× solar margin, poor-sun worst case is short by ~140 Wh | drive-energy report §2–3 |
| RTK fix over the actual lawns | Not tested | 🟡 Open sky reported; untested near trees and buildings | — |
| Ryobi deck: mass, size, blade switching | Estimates (17 kg, 580 mm housing) | 🔴 Unknown model and wiring | — |

## 2. What simulation found and fixed

These were caught in software, with nothing bought, broken, or mown wrong. Details are in [software/sim/README.md](../../software/sim/README.md#what-simulation-found-and-what-changed-because-of-it).

1. **Fence avoidance stalls edge mowing.** ArduPilot's 2 m avoidance margin → avoidance limited to proximity sensors.
2. **Corner-cutting into trees.** Extra 0.25 m obstacle clearance; fences at the body-contact line; tighter waypoint radius.
3. **Waypoint hunting.** Stripe-end waypoints 3 cm apart made the robot pivot for minutes → the planner merges legs shorter than 0.3 m.
4. **Uncut strips.** With realistic tracking, the pass overlap needed to grow from 7.5 to 15 cm.
5. **Blind driving after GPS loss.** About 8 m of dead-reckoning → the robot now pauses after 2 s and resumes automatically.
6. **Fence storage limit.** A full zone's fence exceeded ArduPilot's 84 points → the planner now fits fences in 80 points.
7. **A planned route through a tree.** A planner bug, caught by a clearance check → replaced by a visibility-graph router; every leg is now verified ≥ 0.17 m from no-go zones.
8. **Operating time.** About 17 h/week with one deck at 0.6 m/s, 8 h/week with two, which changes the twin-deck priority (below).

## 3. Before buying the main parts: four de-risking tests

In this order. Each feeds a number back into `params.py`, `drive_energy.py`, or `coverage.py`, and the reports regenerate.

| # | Test | Buy | ~$ | Answers | Decides |
|---|---|---|---|---|---|
| **T1** | **One razor disc on the bench and on the lawn.** One brushless disc motor + driver, one disc cut from `razor-disc.dxf` with three razor blades, run from the bench supply at 36 V: measure current while cutting a maintained lawn (push it on a hand frame or the deck plate), and while cutting a week's growth. Time the stop after power-off. Also measure one solar panel's midday output lying flat. | 1 disc motor + driver, blades, 1 panel | 80–150 | **Cutting power per disc** (sets the solar balance), blade stop time, panel yield | Pack size (10 vs 15 Ah), disc count, whether a blade brake is needed |
| **T2** | **RTK on a cart.** Set up the base station (guide), put the rover GPS + flight controller on a wheelbarrow, and walk every lawn edge, tree, and bed. | Wave 1 GNSS kit (needed anyway) | (700–900) | RTK fix availability across the real lawns; the **real lawn file** | Real mowing hours and coverage per zone; where the robot can't mow; dock location |
| **T3** | **One hub motor + one VESC on the bench.** Run VESC motor detection (torque constant, resistance), check the axle flats and dropout spacing, test smooth low-speed Hall FOC at 45 rpm, run **30 minutes at mowing torque** (≈ 4–6 N·m: drag a weighted tire or sled) and measure motor temperature, and test the VESC timeout brake. | 1 hub motor + 1 VESC + current-limited bench supply | 210 + 60 | Whether hub motors run cool at mowing speed; real torque constant; braking rate for the bumper calculation | Buy the second motor, or switch to geared or wheelchair motors; final fork-plate DXF; VESC current limits |
| **T4** | **One caster.** Measure the bolt pattern, height, and swivel offset. | 1 caster (need 2 anyway) | 35 | Caster geometry | Caster plate DXF and frame height |

**Then:** cut the plates and order Wave 2 (frame, second motor and VESC, electrical, battery), with every DXF and the battery choice based on measured parts.

## 4. Risk register

| Risk | Likelihood | Impact | Status | Retire by |
|---|---|---|---|---|
| Razor-disc power higher than assumed on farm turf → solar can't keep up | Medium | Medium | 🔴 Open | **T1**; fallback is a bigger pack and occasional mains charging |
| **Robot fails to keep up** (rain week, breakdown) and razors can't cut the backlog | Certain, sometimes | Low | 🟡 Known | The Ryobi/Swisher catch-up mow is part of the operating model |
| Hub motors overheat at mowing speed | Low–medium | High | 🟡 Open | **T3** (fallback: wheelchair or geared motors; frame accepts swappable drive modules) |
| RTK float/no-fix near buildings and trees | Medium | Medium | 🟡 Open | **T2**; the robot pauses on fix loss (SITL-verified) |
| Path tracking on grass worse than ±10 cm → uncut strips | Medium | Low (one more overlap step) | 🟡 Open | Phase 1b field tuning; overlap is one planner parameter |
| Braking on wet grass < 3 m/s² → bumper speed limit < 0.6 m/s | Medium | Medium | 🟡 Open | T3 brake test, then commissioning step 7 |
| Single deck too slow for 3 acres weekly (≈17 h) | High | Medium | 🟡 Known | Twin decks (≈8 h), already designed in; buy the second used Ryobi early |
| Frame or joint failure | Low | High | ✅ Analysed | Gussets, saddle forks, torque arms; check bolt preload after the first hours |
| Autopilot logic error (blade on outside AUTO, no stop on faults) | Low | High | ✅ SITL 13/13 | Re-run `run_sitl.py` after every parameter or script change |
| Mission or fence too large for the flight controller | Low | Medium | ✅ Resolved | SD-card mission/fence storage + planner budget |
| Cost overrun | Medium | Medium | 🟡 | De-risking tests buy parts needed anyway; the battery waits for T1 |

## 5. Decision points

- **After T1:** pack size (10 or 15 Ah) and disc count from the measured disc power and panel yield.
- **After T2:** confirm 3 zones (or more) and the dock location; regenerate plans from the real lawn file.
- **After T3:** commit to hub motors, or switch drive modules before buying the second motor.

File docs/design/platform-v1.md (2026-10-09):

# Orbitist Farm Robot — Platform v1 Design (Brainstorm)

*Status: draft for discussion · Started 2026-10-08 · Builds on the [Sept 2026 vineyard concept report](../concept/2026-09-vineyard-robot-design-report.pdf)*

## 1. What we're building this winter

A single, open-source, farm-buildable robot base that **mows our lawns autonomously by spring**. It should also be able to grow into the long-term jobs: towing small loads such as mulch, carrying sensors, and eventually carrying a light arm for weeding and pruning.

Design rules:

1. **Buy what's proven, build what's simple.** Use parts with large hobby or ag communities behind them, such as e-bike and scooter parts, mower replacement parts, ArduPilot autopilots, and u-blox RTK GPS. Only fabricate brackets, plates, and frame cuts.
2. **Salvage-friendly.** Every major subsystem has a "new part" path and a "salvaged part" path.
3. **One robot first.** Get one robot doing useful work before building a pair or a fleet.
4. **Safety is a subsystem, not a feature.** This robot carries a spinning blade, so the kill chain gets designed before the autonomy.

## 1a. Site parameters (our farm)

| Parameter | Value | Design impact |
|---|---|---|
| Lawn area | **~3 acres (~12,000 m²)**, growing as the farm expands | One 21" deck needs ~12.5 h per full pass at v1's 0.6 m/s, so the robot must **mow in daily zones from a charging dock** (§5) |
| Existing equipment | Ryobi electric push mower + several Ryobi batteries, in daily use | Mower module uses a **second, used Ryobi deck** of the same voltage line so batteries and charger are shared (§6.2) |
| Fabrication | Any tools needed | Extrusion for fast iteration; welded steel and outsourced laser/water-jet plates where they're stronger or cheaper |
| Connectivity | Cell coverage over the whole property; Wi-Fi can be extended | Telemetry and remote monitoring over Wi-Fi/LTE later; RTK corrections can travel over radio or network |
| RTK correction service | **None known nearby** | **Our own RTK base station** on a farm building is required in phase 1. It serves every future robot on the farm. |
| Terrain | **Generally flat** | Rear-wheel drive with front casters has plenty of grip; 4WD is only needed for hauling in mud later |
| Sky view | **Open sky; base station can go anywhere** | Ideal for RTK: expect a solid fix nearly everywhere. Put the base near the middle of the lawns. |
| Layout | **Mostly open lawns joined by ~8 ft (2.4 m) paths**; small paths touched up by hand | Robot can be up to ~1.4 m wide, so the frame is **built wide enough for twin decks from the start** (§4) |
| CAD | Open to anything | **Code-based CAD (build123d) in the repo**; STEP exports open in Onshape or FreeCAD (§6.6) |
| License | Delegated to Claude | CERN-OHL-W-2.0 (hardware) · Apache-2.0 (software) · CC BY-SA 4.0 (docs). See [LICENSE.md](../../LICENSE.md). |

## 1b. Revision of 2026-10-09: daily razor cutting and a solar roof

After the [form-factor exploration](form-factor-exploration.md), v1's cutting system and energy supply changed. The chassis, drive, casters, bumper, safety chain and navigation did not.

| | Was (Ryobi deck) | Now (v1 baseline) |
|---|---|---|
| Cutting | one 21" Ryobi deck at 150–400 W, weekly-capable | **four Ø280 mm razor-blade discs** on ~100 W brushless motors, 10–20 W each, cutting a few mm of regrowth daily; **1.06 m symmetric cut** |
| Mowing hours, 3 acres weekly | ~17 h (single) / 8 h (twin) | **~7.3 h/week, ~1.2 h/day** |
| Energy per day | 0.9–2.1 kWh | **~0.25 kWh typical, 0.64 worst** |
| Supply | 36 V 20–40 Ah pack + charging dock (phase 2) | **~220 W solar roof + 36 V 10–15 Ah pack, no dock**; parks in the sun |
| Tall growth / spring | the deck handles it | **the farm's Ryobi or the Swisher**, by hand, before the robot takes over |
| Deck mass | ~17 kg (34 twin) | ~10 kg |
| Robot mass | 73 / 91 kg | ~78 kg including the roof |
| GNSS antenna, e-stop | on the frame | on the roof's rear rail (clear sky, reachable) |

The twin-Ryobi layout stays in the CAD as the `twin` configuration for anyone who needs weekly-capable cutting; `razor` is the default.

## 2. What changes from the vineyard concept, and why

The concept report is a good foundation. Its research on hub motors, the 36 V bus, e-bike packs, AprilTags, and the risk table carries over. Mowing as the first task and towing and arm work as later tasks change what matters most.

| Topic | Concept report | v1 proposal | Why |
|---|---|---|---|
| Number of robots | Identical pair with peer-to-peer docking | **One robot.** Peer docking becomes a later research track. | Mowing doesn't need two robots, and the dock latch was the highest-risk item (Risk #1 in the report). |
| Navigation | AprilTag + odometry; RTK GPS in phase 3 | **RTK GPS from day one** | Coverage mowing needs ~2–5 cm repeatable position across open lawn. Every DIY and commercial wire-free mower relies on this. |
| Low-level control | Pi 5 + ROS 2 + `ros2_control` | **ArduPilot Rover on a $60–150 flight controller**, with the Pi 5 + ROS 2 added as a companion in phase 2 | ArduPilot already provides skid-steer control, RTK/EKF fusion, waypoint and grid missions, geofences, failsafes, and logging, and people already run it on mowers. This replaces months of ROS 2 integration with days of parameter tuning. |
| Chassis layout | 2WD with front and rear casters, rear docking pin | **Zero-turn layout:** 2 driven rear wheels, 2 front casters, mid-mounted deck | This is the layout lawn mowers settled on. It pivots in place without scrubbing turf, unlike 4WD skid-steer. |
| Motor drivers | Hoverboard mainboard with EFeru FOC | **VESC-class FOC controller per wheel** by default; hoverboard board as the budget option | VESCs take RC-PWM or CAN straight from ArduPilot, handle low-speed hub-motor torque well with Hall sensors, and are documented on the ArduPilot forums. |
| Payload approach | Basket on the top deck | **Three mounting points:** belly (mower deck), rear hitch (towed cart), top deck (sensors/arm) | Towing a garden cart is easier on the robot than carrying a load: the cart's wheels hold the weight, and tongue weight adds traction. |
| Charging | Peer-to-peer bus sharing | **Swapped battery first, then a fixed charging dock** in phase 2 | Lawns sit near buildings. A fixed dock is how commercial mowers work and is much simpler. ArduPilot already has an AprilTag-guided [Dock mode](https://ardupilot.org/rover/docs/dock-mode.html). |
| Battery chemistry | "36 V (10S) LiFePO4" | **36 V means 10S Li-ion (NMC), or 12S LiFePO4 (38.4 V nominal)** | Correction: 10S LiFePO4 is only 32 V. Both 10S NMC and 12S LFP run 36 V-class motors and controllers. |

Ideas from the concept report that carry forward unchanged: the 36 V bus, 10" pneumatic hub motors, aluminum extrusion with T-slot mounting everywhere, the IP65 electronics box, the e-stop and contactor, the BNO085-class IMU, global-shutter camera + AprilTags (now for the charging dock), and OAK-D Lite for obstacle sensing in phase 2.

## 3. Chassis options considered

| Option | Description | Strengths | Weaknesses | Verdict |
|---|---|---|---|---|
| **A. Zero-turn rover** | 2 rear hub motors, 2 front mower-caster wheels, extrusion frame | Turf-friendly, simple, cheap, mirrors proven mower geometry | Only 2 wheels drive, so traction on wet slopes is limited (see §5) | **v1 recommended** |
| B. Salvaged power-wheelchair base | Used wheelchair ($100–300 on Marketplace) supplies frame, 24 V gearmotors **with electromagnetic brakes**, casters, and wheels | Very high torque, holds position on slopes, very cheap if found | Availability varies; needs a new motor controller (Sabertooth/RoboClaw, $90–130); heavy; 24 V | **Strong salvage alternative.** The frame will accept wheelchair motors as a drop-in "drive module." |
| C. 4WD skid-steer | 4 hub motors, no casters (Amiga-style) | Best traction and mud performance, good for hauling | Scrubs and tears turf when turning; +$250 | **v2 variant for hauling and fieldwork.** Same frame, casters swapped for driven wheels. |
| D. Docked pair (concept report) | Two robots that latch into one 4WD unit | Redundancy and shared range | Highest complexity; not needed for mowing | Research track after v1 works |
| E. Convert an existing riding or zero-turn mower | ArduPilot + actuators on a gas or electric ZTR | Big cutting width, proven by the ArduPilot community | Heavy, dangerous, less reusable as a general platform | Not pursued, but forum builds are a useful reference |

**Modularity choice:** design the frame around **swappable drive modules**. Each drive wheel bolts on through a pair of dropout plates, so Options A, B, and C share one frame.

## 4. v1 layout (top view)

```
              FRONT
     ┌─────────────────────────┐
     │ (caster)       (caster) │   ← 10" pneumatic plate casters on steel corner plates
     │    ╔═══════════════╗    │   ← bump bar / bumper switches across the front
     │    ║               ║    │
     │    ║  MOWER DECK   ║    │   ← belly mount, hangs from 4 links, anti-scalp wheels
     │    ║  (mid-mount)  ║    │
     │    ╚═══════════════╝    │
  ███│  [ IP65 electronics ]   │███  ← 10" hub motors in dropout plates (drive axle)
  ███│  [ battery over axle ]  │███
     │        [hitch]          │   ← rear 2" receiver or pin hitch for the cart
     └─────────────────────────┘
              REAR
   RTK antenna(s) on a mast above the deck · e-stop mushroom at rear top
```

Envelope from the [first CAD model](../../hardware/cad/README.md) (`hardware/cad/exports/report.md`, regenerated from `params.py`):

| Parameter | Target |
|---|---|
| Overall width | **1.40 m** over the tires (frame 1.28 m), sized for twin decks from day one. Fits 2.4 m farm paths and vineyard aisles; too wide for a man-door, so store in a garage or barn bay. |
| Length | **1.62 m** bumper foam to hitch pin (frame 1.15 m) |
| Height | **0.86 m** to the antenna on the roof (roof surface at 0.71 m) |
| Frame | 30×30 mm aluminum T-slot (axle and hitch rails 30×60 or steel plate) |
| Wheelbase (drive axle to caster pivots) | 85 cm |
| Frame height | rails 300–360 mm above ground; mower motors poke up through open frame bays |
| Ground clearance under frame | ≥ 15 cm (deck hangs below) |
| Mass, mowing config | **~78 kg** with the razor deck and solar roof (73 kg with one Ryobi deck and no roof; 91 kg with twin Ryobi decks), from the detailed model including brackets, gussets, fasteners, hangers and hitch. |
| Cut width | ~53 cm with one deck in the **rear-right** slot (v1) → **~1 m with twin decks** (v1.5) |
| Closest cut to an obstacle | **~17 cm on both sides** with the razor deck (symmetric); ~19 cm on the right only with the Ryobi deck |
| Cut width (razor) | **1.06 m**, four staggered discs, symmetric about the centreline; ~17 cm from the cut edge to the robot's outside on both sides |
| Mowing speed | **0.6 m/s in v1**, the fastest the bumper can protect ([strength report](../../hardware/cad/exports/strength-report.md#bumper-stopping-distance)). Faster once phase-2 obstacle sensing slows the robot before contact. |
| Top speed (transit) | ~1.5–2 m/s (software limited) |

**What the model showed:**
- **About 70 % of the weight sits on the drive wheels** with the razor deck and roof (the deck sits ahead of the axle), ~80 % with a Ryobi deck. Good traction either way on flat ground; the casters carry 15–25 kg.
- **Tongue-weight limit:** a cart pressing down on the hitch more than **~50 kg** (razor + roof) or ~32 kg (single Ryobi deck) lifts the front casters. Carts must be loaded so they're balanced over their own wheels, or the hitch must move closer to the axle. Revisit in phase 3.
- **Twin decks must be staggered,** because two decks side by side would leave a ~5 cm uncut strip. Staggering adds about 33 cm of length.

**Strength check:** see [`strength-report.md`](../../hardware/cad/exports/strength-report.md). It requires torque arms on the hub motors, saddle-mounted drive forks, gussets at the joints next to the drive axle, a 30x60 cross member at x = 215, and an A-frame drawbar before any towing.

**Why build wide now:** on 3+ acres with 8 ft paths, the twin-deck upgrade roughly halves mowing time (§5). Cutting the extrusion 50 cm longer now costs ~$30. Rebuilding a narrow frame later would mean redoing the drive mounts, wiring, and CAD. The twin decks are **staggered** (rear-right, front-left) so their cuts overlap by 5 cm; side by side would leave an uncut strip because the housing is wider than the blade. **v1 runs one deck in the rear-right slot**, not centred. The robot can then edge along beds and fences on its right side, the planner drives laps with the deck facing the boundary, and the twin upgrade only adds the front-left deck.

**Why the battery sits over the drive axle:** in a zero-turn layout the casters carry weight without providing traction. Every kilogram over the rear axle helps on slopes, as §5 shows.

## 5. Back-of-envelope sizing

Assumptions: 45 kg robot, 10" (0.254 m) wheels, rolling-resistance coefficient on turf ≈ 0.10, 65 % of mass on the drive wheels.

**Torque on a 15° slope:** grade force 45·9.81·sin15° ≈ 114 N, plus rolling resistance ≈ 44 N, gives ≈ 160 N total. That works out to **≈ 10 N·m per wheel**. A 36 V 350 W 10" hub motor is typically rated around 10–15 N·m continuous with higher peak, so torque is adequate.

**Traction is the real limit** (a general-user concern; our farm is flat): normal load on the drive wheels ≈ 287 N. With grass friction μ ≈ 0.35 (wet) to 0.6 (dry), the robot can push 100–170 N before slipping. That means **dry 15° slopes are marginal and wet 15° slopes will slip.** The v1 spec is therefore **10° slopes reliably, 15° in dry conditions**, with ballast over the axle as the first fix and the 4WD variant (Option C) as the real one.

**Towing a garden cart:** a 100 kg load in a 15 kg cart on flat grass needs ≈ 113 N, plus the robot's own ≈ 44 N, for ≈ 160 N. That's feasible on dry flat ground, especially with some tongue weight on the hitch. Mulch at roughly 250–400 kg per cubic yard means **partial loads, many trips**. That's fine for a robot that doesn't get tired.

**Wheel speed:** 1 m/s on a 10" wheel is ≈ 75 rpm. Scooter hub motors have a no-load speed around 600–700 rpm at 36 V, so the robot runs at ~10–15 % of motor speed. That's fine **only with Hall-sensored FOC**, which VESC and EFeru firmware both provide. Sensorless control will stutter at low speed.

**Mowing energy:**

| Load | Estimate |
|---|---|
| Drive on turf at 0.8 m/s | ~100–150 W |
| Blade (21" deck, maintained lawn, mowed weekly or more often) | ~150–400 W |
| Electronics (autopilot, GPS, radios, Pi later) | ~20–30 W |
| **Total** | **~300–550 W** |

Coverage at 0.45 m effective swath × 0.8 m/s ≈ **1,300 m²/hour ≈ 1/3 acre per hour** (v1 actually runs at 0.6 m/s, see the table below). A 36 V 20 Ah pack (720 Wh, ~575 Wh usable) gives **~1–1.5 h, or roughly 0.3–0.5 acre per charge**. Ways to extend that:

- Mow more often and cut less each time, as commercial robot mowers do. Blade power drops sharply.
- Run the blade from its own tool battery (see §6), which roughly doubles available energy.
- Use two packs: swap one while the other charges.
- Phase 2: add a charging dock and mow in daily chunks.

**Applied to our ~3 acres, from the coverage planner calibrated against simulation** ([sample-farm plans](../../software/sim/plans), [drive-energy report](../../hardware/cad/exports/drive-energy-report.md)):

| Configuration | Mowing time per week (≈3 acres) | Per day (6 days) | Energy per day (typical / worst) |
|---|---|---|---|
| **One deck, 0.6 m/s (v1)** | **~17 h** | ~2.8 h | ~1.1 / 2.1 kWh (drive + blade) |
| **Twin decks, 0.6 m/s (v1.5)** | **~8 h** | ~1.3 h | ~0.9 / 1.6 kWh |
| Faster (1.0 m/s) | needs phase-2 obstacle sensing: the bumper only protects ≤ 0.6 m/s | | |

These include two perimeter laps, 15 cm pass overlap, pivots at every stripe end, and transits around trees. They're about 35 % longer than the first back-of-envelope estimate.

So the operating model is **mowing a zone each day from a charging dock**, the way commercial robot mowers work.

Consequences:
- **Twin decks matter more than first thought.** One deck needs nearly 3 h a day. **Buy the second used Ryobi early** (see [confidence plan](confidence-plan.md) T1).
- **The blade is the energy driver,** and its power is still a guess. One deck from Ryobi packs means **4–5 pack swaps a day**, which is impractical. Moving the deck onto the robot pack, and the battery size, are decided after measuring the blade (T1). A 20 Ah pack covers the drive only.
- **The charging dock** is still the first item in phase 2.
- **Open sky** means RTK should hold a fixed solution almost everywhere. The robot pauses automatically if it doesn't (§6.3).

## 6. Subsystems

### 6.1 Drive

| | Default (new) | Budget | Salvage |
|---|---|---|---|
| Motors | 2× 10" pneumatic hub motor, 36 V 350–500 W, **Hall sensors**, double-sided axle | same | Power-wheelchair gearmotors with brakes (24 V) |
| Controller | 2× VESC-class FOC (e.g. Flipsky 4.20/6.x, Makerbase 75100 class), RC-PWM or CAN from ArduPilot | 1× hoverboard mainboard + [EFeru FOC firmware](https://github.com/EFeru/hoverboard-firmware-hack-FOC), PWM/PPM variant, **tank mixing off** | Sabertooth 2x32 or RoboClaw 2x30 |
| Casters | 2× 10" pneumatic **plate-mount** swivel casters (4"×4.5" top plate) on 8 mm steel corner plates: bolt-on, no welding | same | Zero-turn mower casters from a junked rider (needs a welded spindle housing) |

Mechanical notes from the e-bike world:

- **Torque arms.** Hub-motor axles spin out of plain slotted plates under load and shred the wires. Use 6 mm aluminum or 5 mm steel dropout plates with the axle flats in a snug slot, plus torque washers.
- **No parking brake.** Hub motors roll freely when unpowered. The VESC can hold position while armed, but on power loss a hub-motor robot will roll downhill. Park on the flat, or add a solenoid or caliper brake later. Wheelchair motors don't have this problem.

### 6.2 Mower module

The mower is a **module that bolts to the belly mount**, not part of the robot. Options:

| Option | How | Pros | Cons | Verdict |
|---|---|---|---|---|
| **M1. Salvaged cordless mower** (Greenworks/Ryobi/Kobalt "40 V max" class) | Remove handle and wheels, hang the deck from the robot, have the robot switch the mower's own start/bail circuit through a relay | Deck, blade, motor, **built-in blade brake**, and height adjust are all included; used units are cheap; 40 V-max tools are 10S, the same voltage class as our bus | Each brand's safety interlock is different; tool-battery data handshakes may complicate running from our pack | **v1 recommended.** Simplest path to cutting grass. |
| M2. Robot-mower-style blades | 1–3 small brushless motors with pivoting razor blades | Safest, quietest, lowest power | Needs frequent mowing; struggles in tall grass | Good later for areas near people |
| M3. Gas push-mower deck + brushless motor | Free curbside deck; replace the engine with a ~1–2 kW outrunner + VESC with brake | Strong cut, most salvage-y | Must build our own blade brake and guarding; keep blade tip speed under the ANSI 19,000 ft/min limit | Fallback / v2 heavy-grass deck |

**Our M1 plan, Ryobi:** buy a **second, used Ryobi mower** of the same voltage line as the one already in use, so the farm keeps its daily mower and the robot shares its batteries and charger. Used Ryobi 40 V mowers are common on Marketplace, often sold without a battery for $50–150. Prefer a brushless model with a mulching deck.
- *To confirm:* model number of the current mower. Ryobi sells 40 V, 80 V, and 18 V ONE+ (twin-battery) mowers, and the voltage decides compatibility. 40 V is the best match: it's 10S, the same class as our drive bus.
- *Bench test:* how the mower's start button and bail switch are wired, and whether it starts from a bench supply or 3D-printed battery adapter without a battery data handshake. This decides phase 2 below.

**Power for M1, phase 1:** the blade runs **from Ryobi batteries we already own**. That keeps the blade electrically isolated from the drive bus, avoids handshake problems, and adds energy. A 40 V 6 Ah pack (~216 Wh) runs a 21" deck for roughly 40–60 minutes. The robot only controls a relay that is part of the kill chain (§6.4).

**Phase 2, once the dock exists (or sooner, see §5):** feed the deck from the robot's main bus through a Ryobi battery adapter so the dock recharges everything, removing the need to swap Ryobi packs every day. This depends on the bench test above. If the mower requires a battery handshake, keep a Ryobi pack on the deck and charge it on the dock with a Ryobi charger.

**Deck suspension:** hang the deck on four short links or chains with anti-scalp wheels, as mid-mount riding mowers do. The deck then follows the ground and doesn't scalp on bumps.

### 6.3 Navigation and control

```
                 ┌──────────── RTK corrections (NTRIP over Wi-Fi/LTE, or own base via radio) ─┐
                 ▼                                                                             │
 [u-blox ZED-F9P rover GPS] ──► [ArduPilot Rover flight controller] ──PWM/CAN──► [VESC L] [VESC R]
 [2nd F9P for GPS-yaw, opt.]─►        │  │  │                                     [blade relay]
                                      │  │  └── RC receiver (ELRS) ← manual drive + arm switch
                                      │  └───── telemetry radio ↔ Mission Planner / QGroundControl
                                      └── MAVLink/DDS ──► [Pi 5 + ROS 2] (phase 2: camera, obstacles, dock, arm)
```

- **Autopilot:** ArduPilot Rover 4.6.x on a Pixhawk-class or Matek H743-class board. Set it up as a skid-steer rover (`SERVO1_FUNCTION=73` throttle-left, `SERVO3_FUNCTION=74` throttle-right). Use a **switch** to arm, never stick arming. ArduPilot's built-in IMU covers tilt and lift detection.
- **GPS:** u-blox ZED-F9P board + survey-grade multiband antenna on a mast. **Heading:** compasses do poorly near hub-motor magnets and steel. ArduPilot supports **GPS-yaw (moving baseline)** with two F9Ps about 50 cm or more apart, which is the recommended upgrade if heading proves noisy.
- **RTK corrections: our own base station** (no known service nearby). Step-by-step setup: [`docs/guides/rtk-base-station.md`](../guides/rtk-base-station.md).
  - **Hardware:** a ZED-F9P + survey multiband antenna on a fixed mount with clear sky, on a barn or house roof or a post. Power and a small enclosure.
  - **Absolute position:** let the base "survey in," or better, log 24 h of raw data and submit it to the free **NOAA OPUS** service or a PPP service. That fixes the base's coordinates, so lawn maps and fences stay accurate even if the base is moved or replaced.
  - **Link to the robot, v1:** a 915 MHz telemetry radio straight from the base to the rover GPS. No network or internet needed. SiK-class radios cover typical farm distances easily.
  - **Link, later:** a Raspberry Pi at the base runs an NTRIP caster (e.g. RTKLIB `str2str`) over farm Wi-Fi or LTE. Any number of robots, a tractor, or survey gear can use the same corrections.
  - One base covers everything within ~10 km, so it serves the whole farm as it expands.
  - *Worth a 10-minute check:* look for a state DOT CORS station or community RTK2go base within ~20 km. If one exists, it's a free backup.
- **Mowing patterns: our own planner** ([`software/sim/coverage.py`](../../software/sim/coverage.py)). It runs two perimeter laps with the deck facing the boundary, then stripes at the angle with the fewest turns. It routes around trees and beds with a visibility graph, keeps every leg ≥ 0.17 m from the no-go fences, and writes one mission and one fence per zone (Mission Planner and QGroundControl formats). Mission Planner's generic grid tool doesn't know about the offset deck, the robot's width, or obstacle clearance.
- **Blade control** goes through a Lua interlock ([`blade_interlock.lua`](../../software/ardupilot/scripts/blade_interlock.lua)): missions *request* the blade, and the script switches the relay only when armed, in AUTO, with an RTK fix, inside the fence, level, and with the e-stop loop OK. It also **pauses the mission if RTK is lost for 2 s** and resumes when the fix is back. Without that, ArduPilot dead-reckons ~8 m before its own failsafe (found in simulation).
- **Simulation (set up):** ArduPilot Rover 4.6.3 SITL runs our parameter file, the Lua script, and the planned missions through acceptance tests (mission, RC loss, e-stop, restart, GPS loss, fence). **13/13 pass.** It found eight problems before any hardware existed; see [`software/sim/README.md`](../../software/sim/README.md) and the [confidence plan](confidence-plan.md).
- **Tree cover:** RTK degrades to "float" under trees and near buildings. v1 mows open areas only and pauses when the fix drops. Phase 2 adds wheel odometry and camera-based fallback for edges.

### 6.4 Safety and kill chain

*Detailed design, wiring, and commissioning tests: [`hardware/electrical/README.md`](../../hardware/electrical/README.md). Wireless e-stop firmware: [`software/estop_receiver`](../../software/estop_receiver/README.md).*

This is designed first and tested on the bench before the blade is ever installed.

1. **Hardware e-stop loop (normally-closed, series):** mushroom button on the robot → wireless e-stop receiver relay → bumper switches. Any break opens the **main contactor** (drive power) and the **blade relay**.
2. **Wireless e-stop that fails safe:** losing the signal must stop the robot. Use a dedicated receiver (a separate ELRS receiver with failsafe = no pulses driving a relay module, or a commercial industrial wireless e-stop). A simple 433 MHz relay remote is *not* acceptable, because it doesn't fail safe.
3. **Blade interlocks, through the autopilot:** blade only runs when armed, in Auto or Mission mode, with RTK fix, inside the fence, level (tilt < ~25°), and not lifted. A relay output plus a Lua script, or `RELAY` + failsafe actions, cuts the blade the moment any condition fails.
4. **Blade brake:** the M1 mower deck has one built in. For M3 we'd need a VESC brake with a mechanical backup. Target: blade stops in under 3 s.
5. **Geofence** with action = Hold/disarm.
6. **Supervised operation only in v1:** someone is present with the e-stop and no people, kids, pets, or livestock are in the zone. Obstacle detection (OAK-D Lite or a cheap ToF/radar ring) comes in phase 2 before any unsupervised mowing.
7. **Stop, then disconnect (Category 1 stop):** an e-stop first cuts the motor-controller signals so the VESCs brake, then opens the main contactor ~1 s later. Cutting power instantly would let the hub motors coast for ~0.5 m.
8. Precharge, main fuse, per-rail fuses rated for 58 V DC, and fused battery leads.

### 6.5 Electrical

| Item | Spec |
|---|---|
| Bus | 36 V class: 10S Li-ion (42 V max) **or** 12S LiFePO4 (43.8 V max). Check every controller and DC-DC is rated ≥ 50 V. |
| Battery | 36 V 20 Ah e-bike pack with BMS (≥ 30 A continuous), XT90 or Anderson connector, in a slide-in bay over the axle |
| Distribution | Main fuse → key switch → precharge → contactor (e-stop loop) → VESCs; unswitched fused feed → DC-DCs for electronics so logging survives an e-stop |
| Rails | 12 V 10 A (lights, payloads, Pi later via 5 V), 5 V 5 A (flight controller, GPS, receivers) |
| Sensing | Power module or INA226 for bus voltage/current to ArduPilot (battery failsafe) |
| Enclosure | IP65 polycarbonate box, cable glands, conformal-coated boards |

### 6.6 Frame and fabrication

- **30×30 aluminum T-slot extrusion** for the perimeter and top deck. Cut-to-length, corner brackets, no welding. Easy to change through many iterations.
- **Plate parts** (dropouts, caster yokes, hitch plate, deck hangers) from 6 mm aluminum or 3–5 mm steel. Hand-cut and drilled at first, then sent to an online cutting service (e.g. SendCutSend) once the design is stable.
- **3D-printed PETG/ASA** for sensor mounts, cable guides, bumper housings, and the antenna mast base. Avoid PLA outdoors.
- **CAD: code-based, in the repo.** The frame is a parametric [build123d](https://github.com/gumyr/build123d) model ([`hardware/cad/`](../../hardware/cad/README.md)). One parameter file drives the STEP assembly, renders, cutting DXFs, extrusion cut list, mass/CG report, and strength check. It's plain text, diffable in git, free for anyone to rebuild, and lets Claude edit it directly. **Onshape** (or FreeCAD) is for viewing the STEP exports and for one-off parts that are easier to sketch by hand; anything drawn there gets exported back to `hardware/cad/`. *Considered:* Onshape as the source of truth (best interactive tool, but its files live outside git and Claude can't edit them); Fusion 360 (personal license is non-commercial only).
- **Standard interfaces**, published as drawings so others can build compatible modules:
  - *Belly mount:* 4 hanger points on a fixed rectangle
  - *Rear hitch:* 2" receiver or 5/8" pin hitch at a fixed height
  - *Top deck:* T-slot rails at fixed spacing, plus a 12 V / 5 V / Ethernet / CAN payload connector

## 7. Roadmap

| Phase | Timeframe | Goal | Exit criterion |
|---|---|---|---|
| **0. Design + sim + de-risk** | Oct–Nov 2026 | ✅ CAD, strength, simulation. **De-risking tests T1–T4** ([confidence plan](confidence-plan.md)): used Ryobi blade-power test, RTK cart survey of the real lawns, one-motor bench test, caster measurements. Then order Wave 2. | SITL acceptance tests pass on the **real** lawn file; battery and drive choices based on measurements |
| **1a. Rolling chassis** | Dec 2026 | Frame, drive, battery, kill chain, RC driving | Drives under RC with a working e-stop; tested on snow/gravel |
| **1b. Autonomy without blade** | Jan–Feb 2027 | Autopilot, RTK, tuning, missions on dormant lawn or snow; **map lawn zones and fences** | Runs a 50×20 m grid, passes within ±5 cm |
| **1c. Mowing** | Apr–May 2027 | Install Ryobi deck module, blade interlocks, supervised mowing with battery swaps | Mows one zone, supervised, with no missed strips |
| **2. Unsupervised-capable** | Summer 2027 | **Charging dock first**, then Pi 5 + ROS 2, obstacle sensing, odometry fallback, deck on main bus | Mows all ~3 acres weekly in daily zones from the dock; stops for a dummy obstacle 10/10 times |
| **3. Hauling** | 2027 | Hitch + cart module, 4WD variant | Moves a cart of mulch along a mapped route |
| **4. Manipulation** | 2028+ | Top-deck arm, perception for weeding and pruning | — |

## 8. Open questions for us to decide

*Answered 2026-10-08:* ~3 acres and growing; Ryobi mower + batteries on hand; any tools available; cell coverage and extendable Wi-Fi; no known RTK service; CAD open to recommendation; flat terrain; open sky; lawns joined by ~8 ft paths; license delegated. See §1a.

Still open, none blocking:
1. **Ryobi voltage line:** check the label on the batteries already on hand (40 V, 80 V, or 18 V) and buy the used robot mower in the same line. If the batteries are 40 V, look for a used **Ryobi 40 V brushless 20–21" mower**, ideally two eventually for the twin deck.
2. **Number of separate lawn zones**, to plan the mowing schedule and choose the dock location. This can be mapped with the robot itself in phase 1b.

## 9. References

- Concept report: [`docs/concept/2026-09-vineyard-robot-design-report.pdf`](../concept/2026-09-vineyard-robot-design-report.pdf)
- ArduPilot Rover: [Dock mode](https://ardupilot.org/rover/docs/dock-mode.html) (AprilTag/ArUco docking via a companion computer); [KevinG's autonomous zero-turn mower](https://discuss.ardupilot.org/t/kevings-autonomous-zero-point-turn-lawn-mower/29178); [first run of a zero-turn mower implementation](https://discuss.ardupilot.org/t/first-run-of-a-nice-implementation-of-autonomous-zero-turn-mower/40501); [skid-steer with VESCs](https://discuss.ardupilot.org/t/three-wheeled-rover-with-skid-steering-and-servo-controlled-tailwheel/34696); [hoverboard boards with ArduPilot](https://discuss.ardupilot.org/t/using-the-boards-from-the-hoverboard-in-autopilot/87229)
- [OpenMower](https://github.com/ClemensElflein/OpenMower): open-source RTK robot mower (ROS, xESC motor control). Good reference for mower-specific software, though its hardware is tied to a donor mower.
- [Acorn (Twisted Fields)](https://github.com/Twisted-Fields/acorn-precision-farming-rover), [farm-ng Amiga](https://farm-ng.com/): open and commercial ag-rover references from the concept report
- [Fields2Cover](https://github.com/Fields2Cover/Fields2Cover): coverage path planning
- [EFeru hoverboard FOC firmware](https://github.com/EFeru/hoverboard-firmware-hack-FOC)

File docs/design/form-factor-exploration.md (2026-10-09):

# Form factors for farm robots, from first principles

*2026-10-08. A step back before buying parts: is a 90 kg wheeled tool-carrier the right shape of robot for a farm that is heading toward polyculture? This document reasons from physics and economics rather than from existing products, scores the candidate form factors against the work a farm actually needs done, and ends with what it changes for Orbitist v1.*

## 1. What farm work is, physically

Every task on a farm is one of five physical operations, applied at a place and a time:

| Operation | Examples | What it costs physically |
|---|---|---|
| **Cut** | mow, prune, harvest, chop-and-drop | energy per unit of material severed; force scales with stem thickness² |
| **Move mass** | mulch, compost, water, harvest, amendments | energy ∝ mass × distance (plus rolling losses); throughput ∝ payload × speed / trip length |
| **Place** | seed, transplant, drip emitters, stakes | precision positioning of small items; low force |
| **Sense** | plant state, weeds, pests, soil moisture, growth | almost free: a camera is $20 and compute is cheaper every year |
| **Protect** | weed, deter pests, shade, cover, net | mostly small forces, high frequency, per-plant decisions |

Two things fall out immediately:

1. **Sensing has decoupled from actuation.** Nothing says the thing that looks at a plant must be the thing that acts on it. A fixed camera can watch 100 m² for years for $20; the actuator can be anything dispatched later. Most robot designs bundle both into one expensive mobile body because that's what a human is.
2. **Non-contact actuation avoids the hard problem.** Dexterous manipulation in clutter (picking a tomato among leaves, pulling one weed from a seedling row) is still unsolved at any price. Laser, flame, spray, water, light, sound and mowing need no grasping. Any form factor that relies on non-contact tools can work *now*; any that relies on hands is a research project.

## 2. Scaling laws that decide the body size

**Square-cube.** A robot half the size has ¼ the panel area and footprint but ⅛ the mass, payload and battery. Small robots are cheap, light on the soil, and carry almost no kinetic energy (a 5 kg robot at 0.5 m/s has 0.6 J; it cannot hurt anything). But their wheels are small, and **a wheel cannot climb an obstacle taller than roughly a third of its radius.** A 10 cm wheel is stopped by a 3 cm stick. Polyculture ground is nothing but sticks, stems and ruts. Small wheeled robots need either prepared ground (lawn, beds, paths), rails, cables, or legs.

**Mass-moving throughput.** A swarm versus one hauler, for 100 m trips at 0.5 m/s (400 s round trip):

| | Payload | Trips/hour each | Throughput |
|---|---|---|---|
| 20 ant-robots | 2 kg | 9 | 360 kg/h, if all 20 work |
| 1 robot towing a cart | 100 kg | 9 | 900 kg/h |

Energy per kg·m is similar for both; the hauler wins because payload scales with the cube of size while the swarm's cost scales with count. Ants win only because they are free. **Swarms are the wrong shape for moving mass.**

**Cutting energy depends on the regime, not the robot.** Mowing energy is set by how much plant material is severed per square metre, which depends on how often you cut:

| Regime | Blade power | Energy per m² | 3 acres per pass |
|---|---|---|---|
| Weekly cut, 21" rotary deck (our v1 plan) | 150–400 W at 0.27 m²/s | ~0.3 Wh/m² | ~3.7 kWh |
| Daily "increment" cut, razor-disc deck (how robot mowers work) | 25–60 W at ~0.1 m²/s | ~0.1 Wh/m², and the cut is 2 mm of regrowth instead of 50 mm | ~1.2 kWh |

This is the single most important number in this document: **cutting little and often needs 3–10× less energy than cutting a week's growth,** which is why a 10 kg Husqvarna with three razor blades mows what a 30 kg petrol mower mows. We adopted the daily-zone schedule but kept the heavy deck; §6 revisits that.

**Slow is cheap.** Power, force, structure, bumper energy and battery all scale with speed, and a robot that has all day can go slowly. The work in §1 mostly has no deadline measured in minutes. A robot that runs ten hours a day at 0.1 m/s does the same work as one that runs one hour at 1 m/s, with 1/10 the power, a fraction of the mass, and no collision risk worth the name. The commercial robots that actually work unattended (ecoRobotix AVO, Husqvarna/EPOS, FarmDroid) are all slow, light, and often solar.

**Solar closes the loop for slow robots.** A 1.3 × 1.5 m robot roof carries about 2 m² of panel, ~300 W peak, ~1.2–1.5 kWh on a summer day. That is more than the daily energy for mowing 3 acres weekly in the razor regime (1.2 kWh per pass ÷ 7 days). A slow solar robot needs **no charging dock and no daily battery handling**, which were two of the three hardest items in our phase 2.

## 3. Where autonomy's cost comes from: infrastructure versus intelligence

A robot knows where it is and what to do either because it is clever (RTK GPS, vision, planning) or because the environment is simple (a rail, a wire, a cable, a wall). Our v1 bought cleverness: ~$1,000 of RTK and autopilot, a visibility-graph planner, failsafes for lost fixes. That is the right trade for **open ground** (lawns, fields), where fixed infrastructure would be absurd.

For **structured ground** it is the wrong trade. A market-garden bed is a 30" wide strip with permanent paths either side; a vineyard is rows at fixed pitch; a food forest has paths. On structured ground the robot's problem collapses from 2-D (x, y, heading) to **1-D (distance along the bed or row)**, and 1-D needs a wheel encoder and an end stop, not $600 of GNSS. Infrastructure also solves terrain: a robot riding on the paths, on rails laid on the bed edges, or on a cable above, never meets a stick.

Rough cost of "infrastructure" autonomy per unit area on a small farm:

| Infrastructure | Cost | Covers | Notes |
|---|---|---|---|
| Permanent bed paths (you have them anyway) | $0 | all beds | the robot's wheels ride the paths; localization by encoder |
| Lightweight rails on bed edges (conduit, angle) | ~$2–4 per metre of bed | one bed per rail pair, or rails moved between beds | FarmBot-style precision at 1/10 the cost per m² |
| Cable-driven head over a plot (4 posts, 4 winches) | ~$1,500–3,000 per plot up to ~0.3 acre | the whole plot, 3-D | no ground contact at all; wind, sag and tension limit the span; proven in research and in camera systems, not yet in farms at scale |
| Trellis wire / irrigation main as a track | reuse | orchard and vineyard rows | the row's own infrastructure carries the robot |
| Boundary wire | ~$0.5 per metre | lawn perimeter | what cheap robot mowers use instead of RTK |

The pattern: **the smaller and more structured the farm, the more infrastructure wins; the larger and more open, the more intelligence wins.** A 3-acre lawn is open ground. A quarter-acre of intensive beds is not.

## 4. The candidate form factors, scored against the work

Scores are for a small, diverse farm like ours, with the honest state of the technology in 2026. ● good · ◐ workable · ○ poor.

| Form factor | Cut (grass) | Cut (woody / harvest) | Move mass | Place | Sense | Protect (weed / pest) | Terrain | Cost to start | Maturity |
|---|---|---|---|---|---|---|---|---|---|
| **A. Wheeled tool-carrier** (our v1: 60–90 kg, RTK) | ● | ◐ with an arm, later | ● towing | ◐ | ● | ◐ | ◐ lawns, paths; not among plants | $2–3k | high (ArduPilot) |
| **B. Slow solar groundskeeper** (20–30 kg, razor deck, 0.1–0.3 m/s) | ● on maintained turf; ○ on tall growth | ○ | ○ | ○ | ● (it's always out there) | ◐ | ◐ | $1.5–2.5k | high (robot mowers) |
| **C. Swarm of tiny ground robots** (≤ 5 kg, many) | ○ | ○ | ○ | ◐ | ● | ● per-plant, non-contact tools | ○ on anything but prepared ground | $0.5–1k each, fleet $10k+ | medium; maintenance of N units is the real cost |
| **D. 1-D bed/row gantry** (rides the paths or rails, straddles a bed) | ◐ paths only | ◐ pruning with a fixed tool head | ◐ along the bed | ● | ● | ● | ● (never leaves the path) | $1–2k | medium; FarmBot/FarmDroid lineage |
| **E. Cable-driven head** over a plot | ○ | ◐ | ○ | ● | ● | ● non-contact | ● (airborne) | $2–3k per plot | low-medium |
| **F. Aerial drone** | ○ | ○ | ○ (seed only) | ◐ seeding | ● | ◐ spot-spray | ● | $0.5–2k | high for sensing |
| **G. Legged (quadruped)** | ○ | ◐ as a platform | ◐ 5–10 kg | ◐ | ● | ◐ | ● | $1.6–3k | low outdoors (water, mud, upkeep) |
| **H. Tethered ground robot** (power cable to a field point) | ● unlimited runtime | ◐ | ◐ | ◐ | ● | ◐ | ◐ | cheapest electrically | medium; tether management |
| **I. Animals + virtual fence** (sheep/geese with GPS collars) | ● orchard floors, understory, zero energy, adds fertility | ○ | ○ | ○ | ○ | ◐ pests (geese, chickens) | ● | $300/collar + animals | high (Nofence, Halter) |
| **J. Human + assist** (follow-me cart, power tools, logging camera) | ● | ● | ● | ● | ● | ● | ● | $1–2k | high |
| **K. Fixed sensing network** (cameras, soil probes, weather) | — | — | — | — | ● continuous, per-plant | enables all of the above | — | $20–50 per node | high |

Reading the table: no single row is good at everything, and the rows that are good at *cut grass* and *move mass* (A, B, I, J) are poor at *place* and *protect*, where D, E, C and K are strong. **The farm needs a system of two or three form factors with shared electronics, not one robot.**

### What each one is really for

- **A, the tool-carrier,** is the mass mover: mulch, compost, harvest crates, water, towing. Its mowing role is the first job because it's the easiest, not because it's the best mower. Keep it.
- **B, the slow solar groundskeeper,** is the best *mower* for maintained turf and could be the same chassis as A with a lighter deck and a solar roof (see §6). It cannot catch up on neglected growth; that's what the Ryobi and the Swisher are for.
- **C, swarms,** make sense where the work is per-plant, non-contact, over a large open area with no infrastructure (a 40-acre arable field) and where losing a few units doesn't matter. Nothing on a small diverse farm looks like that. The *idea* behind swarms that does transfer is **graceful degradation and incremental purchase**: buy one, learn, buy the second.
- **D, the 1-D bed gantry,** is the strongest form for the polyculture future *if the layout has beds or rows.* It is FarmBot without FarmBot's cost per square metre, it never fights terrain, it localizes with an encoder, and its tool head can carry non-contact tools (seeder, water, flame or laser weeder, camera) that work today. It would reuse everything we've built: VESC drive, ArduPilot or a much simpler controller, the safety chain, the same extrusion frame language.
- **E, the cable robot,** is the "place and protect" machine for an intensive plot. It is the most outside-the-box option that could actually be built in a season; it is also the least proven. Worth a bench-scale prototype (4 m × 4 m) before believing in it.
- **F, a drone,** is the cheapest high-value purchase on this list: a weekly orthomosaic of the whole farm at 1 cm/pixel gives weed maps, growth, irrigation faults, and it needs no building. Off-the-shelf, today.
- **G, legs,** are now cheap enough ($1,600 for a Unitree Go2) to be a sensing platform for a food forest, but not reliable enough outdoors to depend on.
- **H, a tether,** is worth remembering for fixed areas: a corded robot mower on a reel has no battery, no dock and no range limit. It isn't absurd for a 1-acre lawn next to a barn.
- **I, animals,** are the zero-energy mower for orchard floors and understory, with fertility as a by-product. A virtual fence makes them "programmable". For a polyculture farm this may be the best mower there is, and it isn't a robot.
- **J, the assisted human,** wins every task that needs judgement (harvest, pruning, planting decisions) for the next several years. A follow-me cart that carries 100 kg and never gets tired is, quietly, the robot most small farms would buy first. It is also our v1 chassis in a different mode: following a person instead of a mission.
- **K, fixed sensing,** is the layer everything else depends on, and the cheapest. It's where "polyculture robotics" should start: knowing what every bed is doing, every day.

## 5. Designing the farm for the robots

The form factor that matters most is the farm's. Permaculture layouts (keyhole beds, guilds, curved swales) are designed for hands and feet. A layout designed for **both** adds three constraints, none of which hurts the ecology:

1. **A lattice of machine-accessible paths** at a fixed width (your 8 ft paths already are one), connecting every zone, so a wheeled carrier can reach anywhere with a load.
2. **Beds or rows at a fixed pitch** where intensive work happens, so a 1-D gantry fits them all.
3. **Edges that are either mowable or grazed,** with a decision per edge: robot B, animals I, or hand tools.

"Robot-ready" is a property of the layout, and it's cheaper to design in than to engineer around.

## 6. What this changes for Orbitist v1

Most of the v1 work survives this analysis untouched: the electronics and software kit (ArduPilot, VESC drive modules, the safety chain, the RTK base, the planner and simulation) is common to A, B, D and H, and the extrusion frame is the right construction method for all of them. Three things change.

**1. The cutting regime, and with it the deck, battery and dock.** We adopted little-and-often mowing but kept a deck built for weekly cuts. If the lawns are mown daily in zones, a **razor-disc deck** (three pivoting blades on a ~250 W brushless motor, running at 25–60 W) does the job at 3–10× less energy. Consequences, from the numbers in §2:

| | v1 as designed | v1 with razor decks + solar roof |
|---|---|---|
| Blade power | 150–400 W per deck | 25–60 W per deck |
| Robot mass | 73–91 kg | ~45–55 kg |
| Daily energy, 3 acres weekly | 0.9–2.1 kWh | ~0.35–0.5 kWh |
| Energy source | 36 V 20–40 Ah pack, **charging dock** (phase 2) | ~300 W solar roof + 36 V 10–15 Ah pack; **no dock**, parks anywhere |
| Catch-up on tall growth | the deck handles it | **cannot**: Ryobi or Swisher for catch-up and spring start |
| Hazard | 21" steel blade, 60 kg | small razor blades, 50 kg: materially safer |

The cost is a dependency: the robot must keep up, every day, in season, or someone mows with the Ryobi. That is exactly the operating model of every commercial robot mower, so it's a known trade. The Ryobi deck remains the right answer if the lawns are often left to grow; the razor deck is the right answer if the robot runs daily. **This is a question about how the farm will operate, not an engineering question, and it should be decided before buying the deck or the battery.**

**2. The order of purchases.** Two of the cheapest items on the list have the highest information value and no build: a **drone** for weekly maps, and a **fixed camera or two** on the beds. They cost less than step 1 of the build and start teaching us what the polyculture robot actually needs to do. They don't delay v1.

**3. The roadmap gains a second platform.** v2 for the polyculture future should not be "v1 with an arm"; it should be the **1-D bed gantry (D)** for whatever beds exist, with non-contact tools, sharing v1's electronics. The arm stays on the roadmap for later, when manipulation catches up.

What does *not* change: v1 remains the mass mover and the first mower; its chassis, drive modules, safety chain and navigation are the right shape for open ground, and nothing above replaces them for hauling mulch across 3 acres.

## 7. Questions only the farm can answer

1. **Will the lawns be mown by the robot daily in season**, or do they sometimes go two or three weeks? (Razor deck vs Ryobi deck.)
2. **What does "polyculture" look like here in five years:** beds at a fixed pitch, an orchard with rows, a food forest without rows, or all three? (Which of D, E, I apply.)
3. **Would animals be welcome** as mowers under trees and on margins? (I is the cheapest mower in the table.)
4. **Is a solar roof acceptable** on the robot (it makes it taller and wider in appearance, and it must park in the sun)?
5. **Is there a quarter-acre plot** where a bed gantry or a cable robot could be prototyped next year without disturbing anything?

## 8. Proposed next moves

1. Decide question 1. If "daily": design the razor deck + solar roof variant in CAD (one evening: it's a lighter deck module and a roof on the existing frame) and rerun the energy, strength and bumper numbers. Step 1 of the build changes: the Ryobi test is replaced by a razor-deck power test, and the bench supply, motor and caster purchases stay the same.
2. Buy a drone (any $500–1,000 camera drone with mapping software) and fly the farm weekly from now. Store the maps in the repo's lawn files.
3. Keep steps 2 and 3 (RTK base, autopilot bench) as planned: they are common to every ground form factor.
4. Sketch the 1-D bed gantry as a v2 design note once question 2 is answered.

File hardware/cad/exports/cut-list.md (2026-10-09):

# Extrusion cut list: platform v1 frame

*Generated by `build.py`; do not edit by hand. Same for single- and twin-deck builds.*

| Profile | Length (mm) | Qty | Total (m) |
|---|---|---|---|
| 30x30 | 300 | 4 | 1.20 |
| 30x30 | 470 | 2 | 0.94 |
| 30x30 | 1150 | 2 | 2.30 |
| 30x30 | 1220 | 5 | 6.10 |
| 30x60 | 1150 | 2 | 2.30 |
| 30x60 | 1220 | 2 | 2.44 |

Buy (with ~10 % for cutting waste): 30x30: 11.6 m, 30x60: 5.2 m

Cross members fit **between** the side rails (frame width 1280 mm minus 2 × 30 mm), joined with corner brackets.

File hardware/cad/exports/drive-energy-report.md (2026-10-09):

# Drive and energy report: platform v1

*Generated by `drive_energy.py`; do not edit by hand. Uncertain inputs are ranges; the **worst end** of each range is used for pass/fail.*

## 1. Hub-motor operating points

Inputs (best / typical / worst): rolling resistance 0.08 / 0.1 / 0.15, torque constant 0.7 / 0.57 / 0.45 N·m/A, phase resistance 0.15 / 0.25 / 0.35 Ω, no-load speed 600 rpm. Copper-loss limit for continuous running at low speed: 60 W per motor.

| Case | Mass | Torque / wheel | Phase current | Copper loss / motor | Battery power (both motors) | Drive efficiency | Thermal (typical / worst) |
|---|---|---|---|---|---|---|---|
| Mowing, flat, 0.6 m/s (v1 razor + roof) | 76 kg | 4.7 / 7.1 N·m | 8 / 16 A | 26 / 131 W | 114 / 388 W | 39 / 17 % | ✅ / ⚠️ |
| Mowing, flat, 0.6 m/s, Ryobi single deck | 73 kg | 4.5 / 6.8 N·m | 8 / 15 A | 24 / 119 W | 106 / 356 W | 40 / 18 % | ✅ / ⚠️ |
| Mowing, flat, 0.6 m/s, twin deck | 91 kg | 5.6 / 8.5 N·m | 10 / 19 A | 37 / 186 W | 149 / 531 W | 36 / 15 % | ✅ / ⚠️ |
| Transit, flat, 1.5 m/s | 91 kg | 5.6 / 8.5 N·m | 10 / 19 A | 37 / 186 W | 243 / 672 W | 55 / 30 % | ✅ / ⚠️ |
| Accelerating 0.5 m/s², twin (seconds) | 91 kg | 8.5 / 11.3 N·m | 15 / 25 A | 84 / 333 W | 292 / 910 W | 28 / 12 % | ✅ / ✅ |
| 10° slope, 0.6 m/s, twin (other farms) | 91 kg | 15.4 / 18.1 N·m | 27 / 40 A | 272 / 852 W | 811 / 2207 W | 18 / 8 % | ⚠️ / ⚠️ |

*Each cell: typical / worst. Worst = high rolling resistance + low torque constant + high resistance all at once.*

At 0.6 m/s the wheels turn at **45 rpm, 8 % of the motor's no-load speed**. Direct-drive hub motors are inefficient this slow, because most of the electrical power becomes copper heat rather than motion. **Verdict: hub motors are adequate for v1 mowing in the typical case**, but the worst-case stack exceeds the 60 W continuous guideline for: Mowing, flat, 0.6 m/s (v1 razor + roof); Mowing, flat, 0.6 m/s, Ryobi single deck; Mowing, flat, 0.6 m/s, twin deck; Transit, flat, 1.5 m/s; 10° slope, 0.6 m/s, twin (other farms). The bench test of one motor (measure Kt and R, run 30 min at the mowing torque on a dyno or towing a load, check motor temperature) retires this risk before buying the second motor. Use Hall-sensored FOC for smooth low-speed torque. A geared motor would be 2–3× more efficient at this speed, but costs more and needs a coupling and a brake. Worth revisiting only if the bench test shows the motor running hot.

**Measure, don't assume:** VESC Tool's motor detection reports the flux linkage (→ torque constant) and phase resistance. Enter them here and re-run.
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

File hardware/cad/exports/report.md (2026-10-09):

# Platform v1 model report

*Generated by `build.py`; do not edit by hand. Masses and many dimensions are ESTIMATES; see `params.py`.*

## Configuration: razor deck

| Quantity | Value |
|---|---|
| Overall length × width × height | 1615 × 1402 × 858 mm |
| Estimated mass | 76.2 kg |
| Centre of gravity (x, y, z) | (224, 41, 324) mm |
| Load on drive wheels | 52.8 kg (69 %) |
| Load on casters | 23.4 kg (31 %) |
| Max cart tongue weight before casters unload | 49 kg (hitch pin 350 mm behind axle) |
| Closest cut to an obstacle, right side / left side | 171 mm / 171 mm (cut edge to the robot's outermost part) |
| Pivot-turn swept radius (about axle centre) | 1377 mm |
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

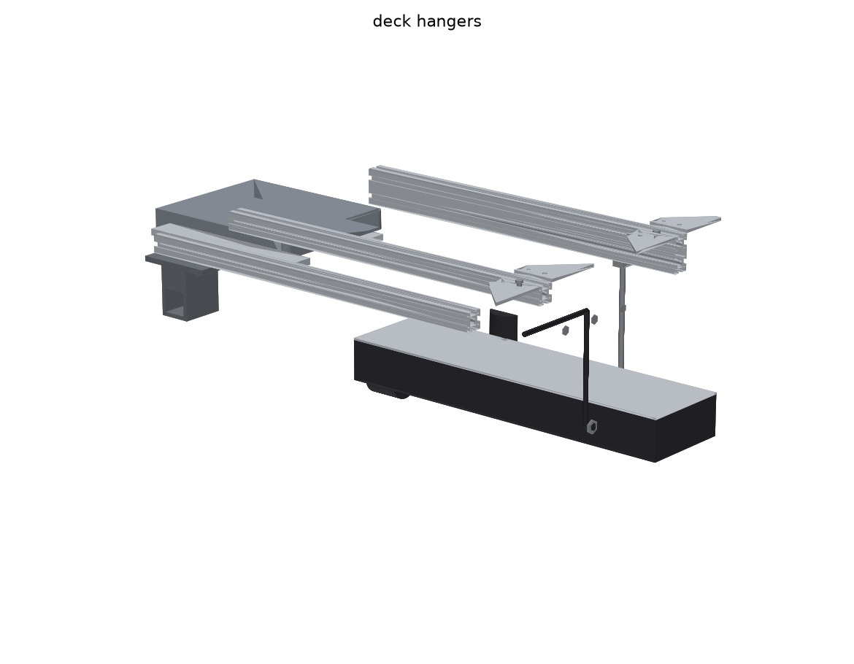
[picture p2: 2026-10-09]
hardware/cad/exports/platform-v1-detail-deck-hangers.png

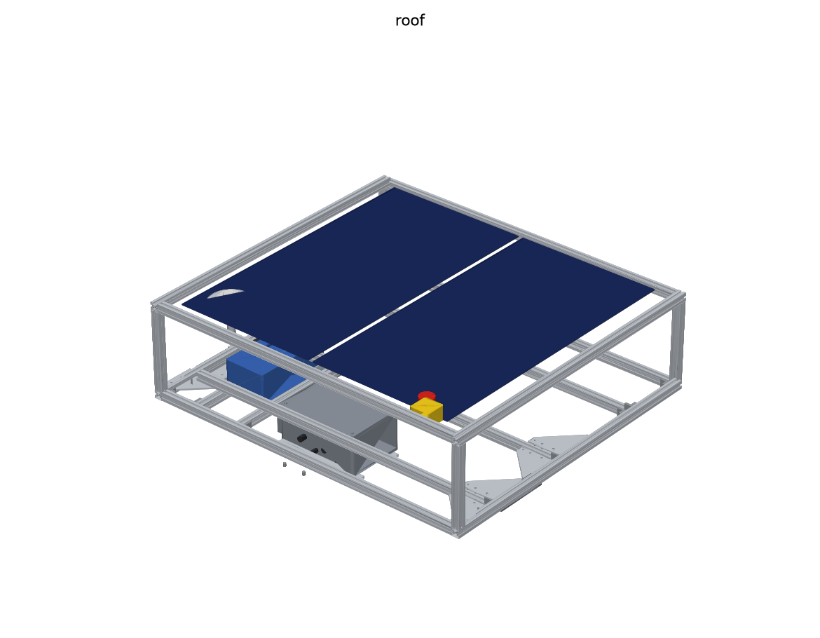
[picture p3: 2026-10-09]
hardware/cad/exports/platform-v1-detail-roof.png

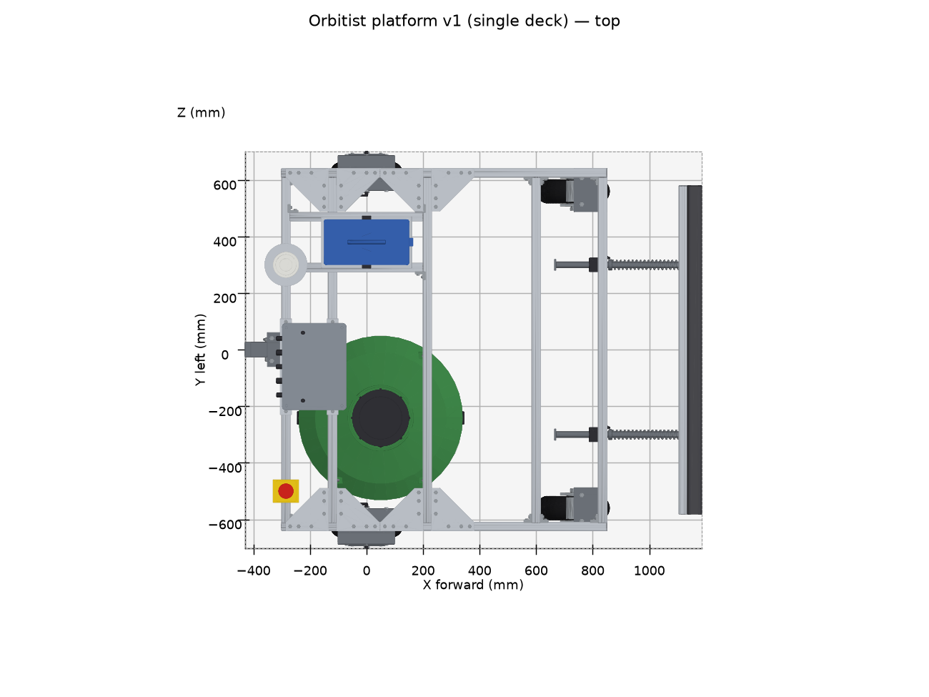
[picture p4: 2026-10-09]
hardware/cad/exports/platform-v1-single-top.png

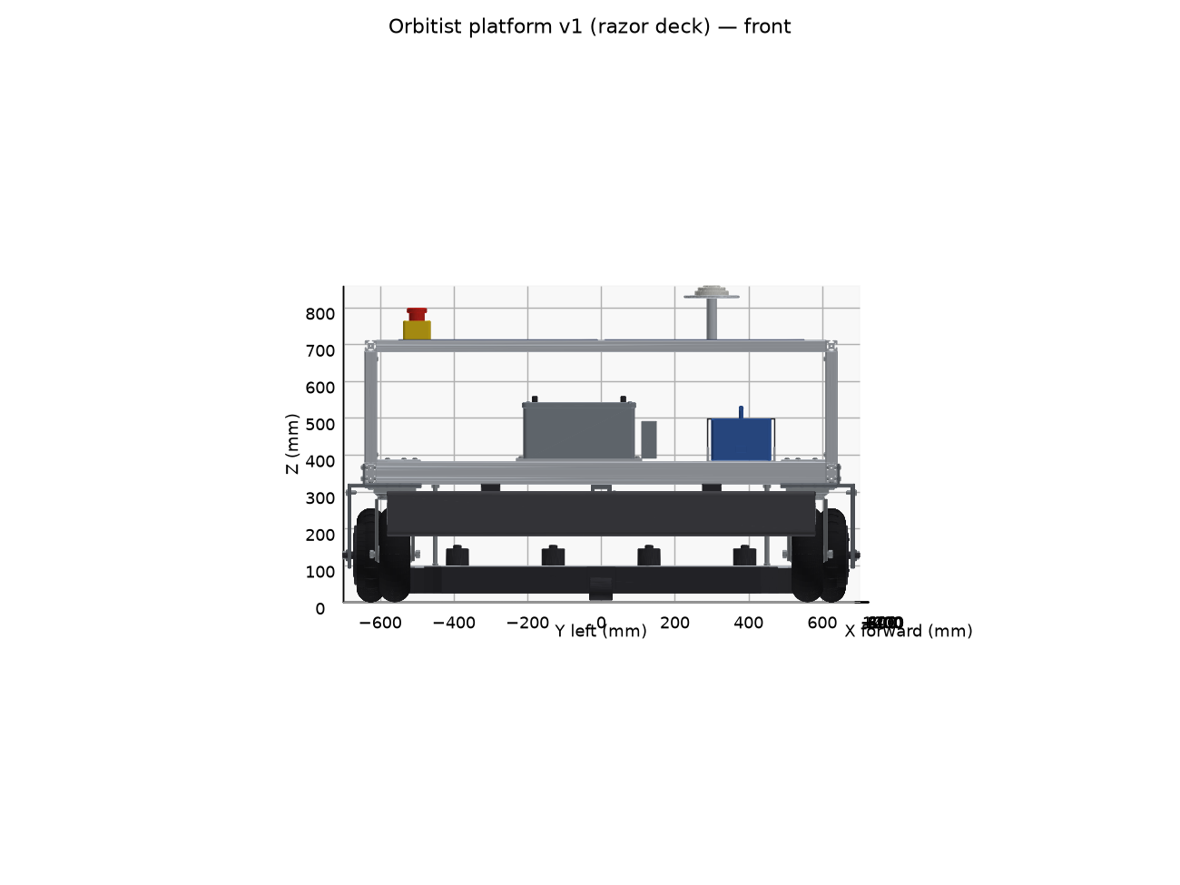
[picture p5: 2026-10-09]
hardware/cad/exports/platform-v1-razor-front.png

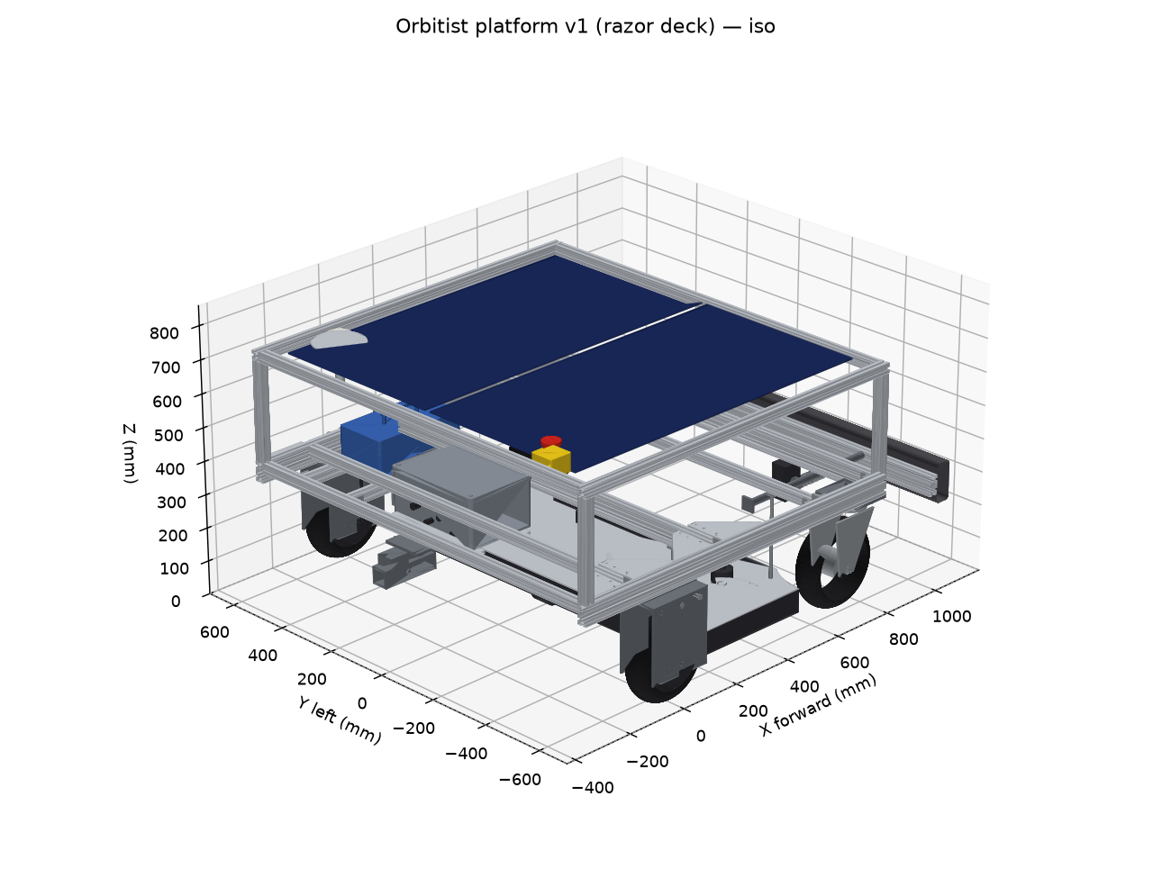
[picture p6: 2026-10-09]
hardware/cad/exports/platform-v1-razor-iso.png

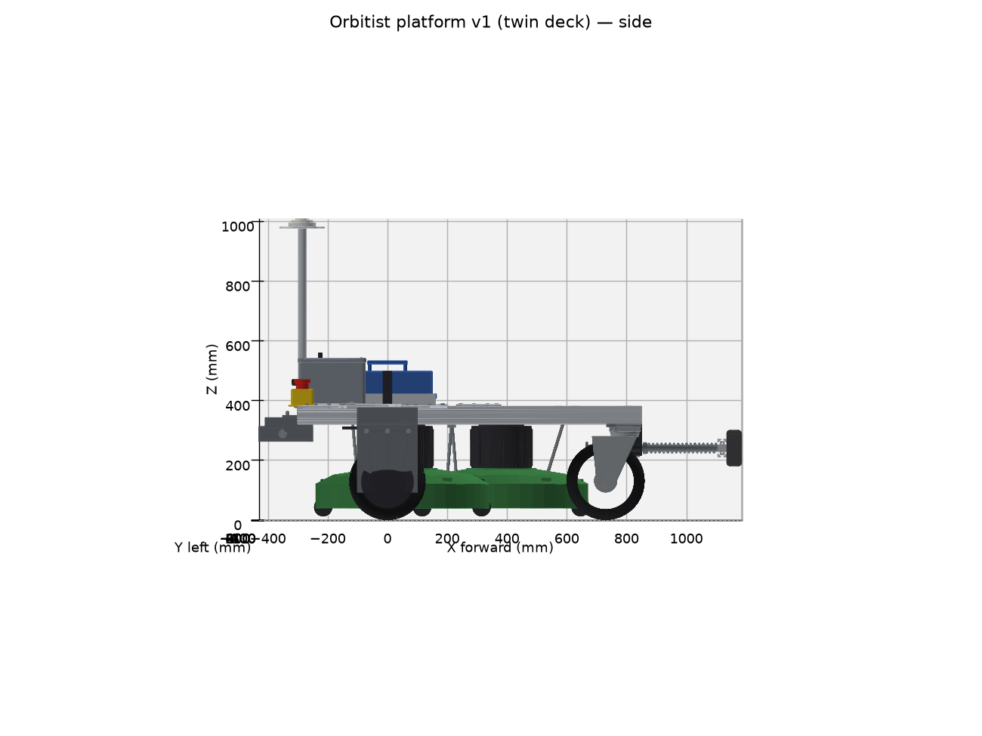
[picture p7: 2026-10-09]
hardware/cad/exports/platform-v1-twin-side.png

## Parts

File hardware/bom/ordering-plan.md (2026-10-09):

# Ordering plan: Platform v1

> The step-by-step version of this, with checked purchase links per step, is the [build tutorial](../../docs/build/README.md). This page stays as the one-screen summary.

Purchases are grouped into waves, so money goes out only when each part is needed and early parts can be tested before the next wave. Prices are rough estimates as of Oct 2026. Full list with costs: [`platform-v1-bom.csv`](platform-v1-bom.csv).

## Wave 0: de-risking tests (now, ~$350, all parts needed anyway)

See the [confidence plan](../../docs/design/confidence-plan.md). These measurements decide the battery, the drive motors, and the final plate DXFs **before** the main order.

| ✓ | Item | Why first | ~$ |
|---|---|---|---|
| ☐ | **One razor-disc unit** (brushless motor + driver, disc from `razor-disc.dxf`, 3 razor blades) and **one ~110 W semi-flexible solar panel** | T1: measure cutting power per disc and real panel yield. Decides the pack size and disc count (D27, D28). | 150–270 |
| ☐ | **One** 10" hub motor + **one** VESC | T3: bench test of torque constant, low-speed smoothness, 30 min thermal at mowing torque, timeout brake. Buy the second only if it passes. | 210 |
| ☐ | Current-limited bench supply (≥ 50 V, 5 A) | Safe first power-up for T1/T3, and later for commissioning | 60–100 |
| ☐ | One 10" plate caster | T4: bolt pattern and height for the caster-plate DXF | 35 |
| ☐ | DC clamp meter (optional) | T1 blade current; useful for the rest of the build | 40 |

## Wave 1: GPS + autopilot (order now, ~$700–900)

**Why first:** the base station needs a day of logging to fix its position. We can also **map the lawn boundaries this fall, before snow**, by putting the rover GPS on a wheelbarrow or garden cart and walking the edges. That map becomes our geofences and mowing zones, and it means navigation is proven before the robot exists.

| ✓ | Item | What to look for | ~$ |
|---|---|---|---|
| ☐ | 2× u-blox **ZED-F9P** boards (base + rover) | ArduSimple simpleRTK2B or SparkFun GPS-RTK2 class. A board with an XBee-style radio socket (ArduSimple) makes the radio link plug-in. | 2× 200–280 |
| ☐ | 2× multiband (L1/L2) GNSS antennas | u-blox ANN-MB class for the rover; a survey-style antenna (or another ANN-MB on a ground plate) for the base | 2× 60–150 |
| ☐ | Radio pair for corrections (base → rover) | 915 MHz SiK telemetry radio pair or an XBee-socket radio pair matching the F9P boards | 60 |
| ☐ | Flight controller | **Holybro Pixhawk 6C (mini)** for easy connectors, or Matek H743 class. Plus a power module rated for 12S. | 120–200 |
| ☐ | RC transmitter + receivers | ExpressLRS (ELRS) transmitter with switches + ELRS receiver for driving + **ELRS PWM receiver** for the wireless e-stop | 100–150 |
| ☐ | Telemetry radio pair (robot ↔ laptop) | Second SiK 915 MHz pair, or MAVLink over ELRS | 60 |
| ☐ | Base station mount | Rigid pole or roof bracket, weatherproof box, 5 V power supply, low-loss SMA cable | 60 |
| ☐ | Raspberry Pi for the base | Pi 4 / Pi 5 / Zero 2 W + SD card + PSU. Logs the 24 h survey and later serves NTRIP. See the [base station guide](../../docs/guides/rtk-base-station.md). | 60–90 |

**Wave 1 tasks:** set up the base station and log 24 h of raw data → submit to NOAA OPUS → enter the fixed base position. Walk the lawn edges with the rover GPS → save the polygons to `software/ardupilot/missions/`. Meanwhile, run ArduPilot SITL on a laptop with those polygons.

## Wave 2: drive and power (after T1–T4, ~$1,100)

| ✓ | Item | What to look for | ~$ |
|---|---|---|---|
| ☐ | Second 10" hub motor (first bought in Wave 0) | 36 V, 350–500 W, pneumatic 10×2.5"–10×3" tire, **Hall sensors (small 5-wire connector)**, **axle with flats on both sides**. Same listing as the Wave 0 motor, so they match. | 120 |
| ☐ | Second FOC motor controller | VESC-class (Flipsky FSESC 4.20 / 6.x, Makerbase 75100), **rated ≥ 50 V**, Hall sensor input, PWM/PPM input. Budget alternative: hoverboard mainboard + ST-Link. | 90 |
| ☐ | 2× 10" pneumatic plate-mount swivel casters | 4"×4.5" top plate, ~12" overall height, ≥ 150 kg rating, ball-bearing swivel. **Measure the bolt pattern and height on arrival** (they set `caster-plate.dxf`). | 2× 35 |
| ☐ | Battery | **Size set by T1** (blade power): 36 V 20 Ah if the deck stays on Ryobi packs; 30–40 Ah (or two 20 Ah) if the deck runs from the robot. BMS ≥ 30 A continuous, plus a matching charger. 10S Li-ion or 12S LiFePO4. | 300–450 |
| ☐ | Electrical | Per the [electrical parts list](../electrical/README.md#7-parts-list-electrical): 40 A MRBF main fuse, battery disconnect, 12 V-coil DC contactor, precharge relay + 47 Ω 10 W resistor, on-delay and off-delay timer modules, DPDT signal relay, 58 V fuses + block, power module, DC-DCs (input ≥ 60 V), XT90s, 10–12 AWG silicone wire | 220 |
| ☐ | Safety | NC mushroom e-stop, Arduino Nano + 5 V relay module (wireless e-stop, [firmware](../../software/estop_receiver/README.md)), 2 roller-lever NC microswitches, optocoupler module | 60 |
| ☐ | Bumper | Aluminium bar or 30x30 extrusion, 2 sliding arms + UHMW/printed guides, return springs, 50 mm closed-cell foam | 50 |
| ☐ | Frame | 30-series slot-8 aluminum extrusion per the [cut list](../cad/exports/cut-list.md): 30×30 3 × 1220 mm; 30×60 2 × 1150 mm + 2 × 1220 mm (buy ~4 m of 30×30 and ~5.2 m of 30×60). Corner brackets, T-nuts, stainless M6/M8 fasteners. | 230 |
| ☐ | Plates | From `hardware/cad/exports/*.dxf`: 4× fork side plates (6 mm steel), 4× **torque arms** (5 mm steel, required), 8× frame gussets (5 mm Al), plus fork top plates and saddle tabs. Send DXFs out for cutting once the motor axle is measured. | 80 |
| ☐ | Enclosure | IP65 polycarbonate box ~30×20×15 cm, cable glands | 70 |

## Wave 3: mower deck (whenever a good deal appears; off-season is cheapest)

| ✓ | Item | What to look for | ~$ |
|---|---|---|---|
| ☐ | Used Ryobi mower #1 | **Same voltage as the farm's existing Ryobi batteries** (check the battery label). Prefer a brushless 20–21" model. A bare tool (no battery) is fine. | 50–150 |
| ☐ | Used Ryobi mower #2 | Same model as #1, for the twin-deck upgrade (v1.5) | 50–150 |
| ☐ | Deck hanging hardware | Links/chain, anti-scalp rollers, a relay to switch the mower's start circuit | 50 |

## Wave 4: phase 2 (spring/summer 2027)

Charging dock, Raspberry Pi 5, OAK-D Lite, global-shutter camera. See the BOM. We'll order these once supervised mowing works.

## Tools to have on hand

- Soldering iron, crimpers (XT90/Anderson, ferrules), multimeter, **current-limited bench supply** (for first power-up of controllers)
- Chop/miter saw with a non-ferrous blade for extrusion, drill press, taps (M6/M8), files
- 3D printer (PETG/ASA filament)
- **ST-Link V2 programmer**, only if using the hoverboard-board option
- Laptop with Mission Planner (or QGroundControl), VESC Tool, and u-center (u-blox configuration)

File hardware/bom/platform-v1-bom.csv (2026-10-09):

subsystem | item | qty | est_unit_usd | est_total_usd | phase | salvage_alternative | notes
drive | 10in pneumatic hub motor 36V 350-500W, Hall sensors, double-sided axle, with tire | 2 | 120 | 240 | 1a |  | Confirm axle flats width and Hall sensor connector
drive | VESC-class FOC controller (Flipsky 4.20/6.x or Makerbase 75100 class), >=50V rated | 2 | 90 | 180 | 1a | Hoverboard mainboard + EFeru FOC (~$45 for both wheels) | RC-PWM or CAN from ArduPilot
drive | Drive fork plates (6mm steel side plates, 8mm top plate, saddle tabs) + torque arms (5mm steel) + 8 frame gussets | 1 | 80 | 80 | 1a |  | DXFs in hardware/cad/exports; torque arms required (strength-report.md)
drive | 10in pneumatic plate-mount swivel caster (4x4.5in plate) | 2 | 35 | 70 | 1a | Zero-turn mower casters (need welded spindle housing) | On 8mm steel corner plates (caster-plate.dxf)
frame | 30x30 aluminum T-slot extrusion, brackets, T-nuts, stainless fasteners | 1 | 230 | 230 | 1a | Steel square tube if welding | Sized for twin-deck width (~1.3-1.4m)
frame | Rear hitch plate + 2in receiver or 5/8in pin hitch | 1 | 40 | 40 | 3
power | 36V 10-15Ah e-bike battery w/ BMS (10S Li-ion or 12S LiFePO4), >=30A | 1 | 220 | 220 | 1a | Salvaged e-bike pack (check cell health) | Solar buffers the day; size confirmed by T1
power | Main fuse (MRBF 40A), battery disconnect, DC contactor, precharge relay+resistor, timer relays, signal relays, 58V fuses | 1 | 160 | 160 | 1a |  | See hardware/electrical/README.md
power | DC-DC 36->12V 10A and 36->5V 5A | 2 | 15 | 30 | 1a |  | Input rated >=50V
power | XT90/Anderson connectors, wire, ferrules, fuse block | 1 | 50 | 50 | 1a
safety | E-stop mushroom switch (NC) | 1 | 15 | 15 | 1a
safety | Wireless e-stop: Arduino Nano + ELRS PWM receiver + relay module | 1 | 40 | 40 | 1a |  | Firmware in software/estop_receiver
safety | Front bumper: bar, sliding arms, guides, springs, foam, 2 NC roller microswitches | 1 | 60 | 60 | 1a |  | 100mm travel; protects up to 0.6 m/s
control | ArduPilot flight controller (Pixhawk 6C mini / Matek H743 class) | 1 | 120 | 120 | 1b
control | RC transmitter + ELRS receiver | 1 | 90 | 90 | 1a |  | Switch-based arming
control | Telemetry radio pair (SiK 915MHz) or ELRS MAVLink | 1 | 50 | 50 | 1b
gnss | u-blox ZED-F9P board + multiband antenna (rover) | 1 | 250 | 250 | 1b
gnss | Second ZED-F9P + antenna for GPS-yaw (optional) | 1 | 250 | 250 | 1b |  | Add if compass heading is unreliable
gnss | RTK base station: ZED-F9P + survey antenna + mount + enclosure + 915MHz radio | 1 | 280 | 280 | 0 |  | Required: no correction service nearby. Fix position via NOAA OPUS.
gnss | Raspberry Pi for base station (logging, later NTRIP) + SD + PSU | 1 | 75 | 75 | 0 | Laptop for the 24h log | docs/guides/rtk-base-station.md
gnss | Radio pair for RTK corrections base->rover (SiK 915MHz or XBee-socket) | 1 | 60 | 60 | 0 | NTRIP over farm Wi-Fi/LTE later | Separate from telemetry radio
electrical | IP65 enclosure, cable glands, belly pan | 1 | 70 | 70 | 1a
solar | Semi-flexible solar panels ~110W (1.05x0.54m) | 2 | 120 | 240 | 1c | Used rigid 100W panels (heavier) | One bought in step 1 for the yield test
solar | Boost MPPT charge controller for 36V battery (Genasun GVB-8 class) + 15A fuse | 1 | 200 | 200 | 1c
solar | Roof: 30x30 extrusion (4 posts + 4 rails), brackets, backing sheet, hinges, gas strut | 1 | 160 | 160 | 1c |  | Carries the GNSS antenna and e-stop
mower | Razor disc cutting units: 4x brushless motor + BLDC driver, 4x Ø280 disc (razor-disc.dxf), 12 razor blades + shoulder screws | 1 | 320 | 320 | 1c | Robot-mower blade motors from a dead Husqvarna/Worx | One unit bought in step 1 for the T1 test
mower | Razor deck plate (3mm Al) + HDPE skirt + hangers + anti-scalp rollers | 1 | 110 | 110 | 1c
compute | Raspberry Pi 5 8GB + cooler + NVMe | 1 | 130 | 130 | 2 |  | Phase 2 companion (ROS 2)
compute | Luxonis OAK-D Lite | 1 | 150 | 150 | 2 |  | Obstacle detection
compute | Pi Global Shutter camera + lens + AprilTag for dock | 1 | 70 | 70 | 2

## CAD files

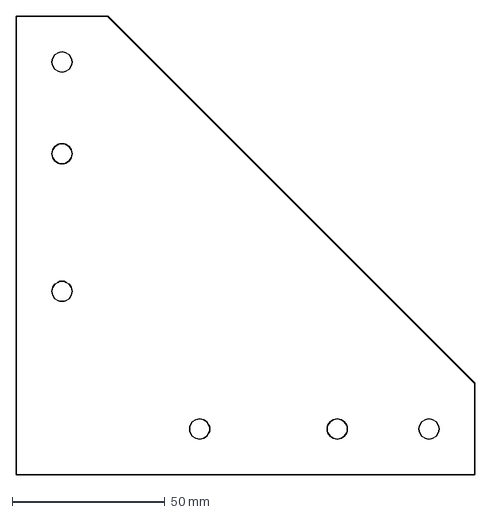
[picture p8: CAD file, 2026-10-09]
hardware/cad/exports/frame-gusset.dxf
150.0 x 150.0 mm

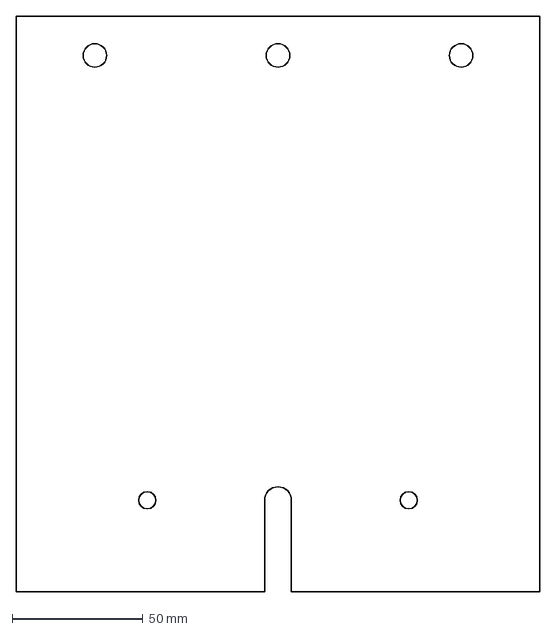
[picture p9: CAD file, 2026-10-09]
hardware/cad/exports/drive-fork-side-plate.dxf
200.0 x 220.0 mm

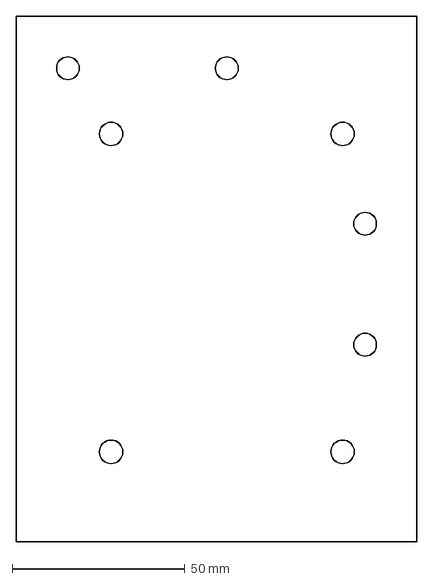
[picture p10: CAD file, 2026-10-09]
hardware/cad/exports/caster-plate.dxf
116.0 x 152.0 mm

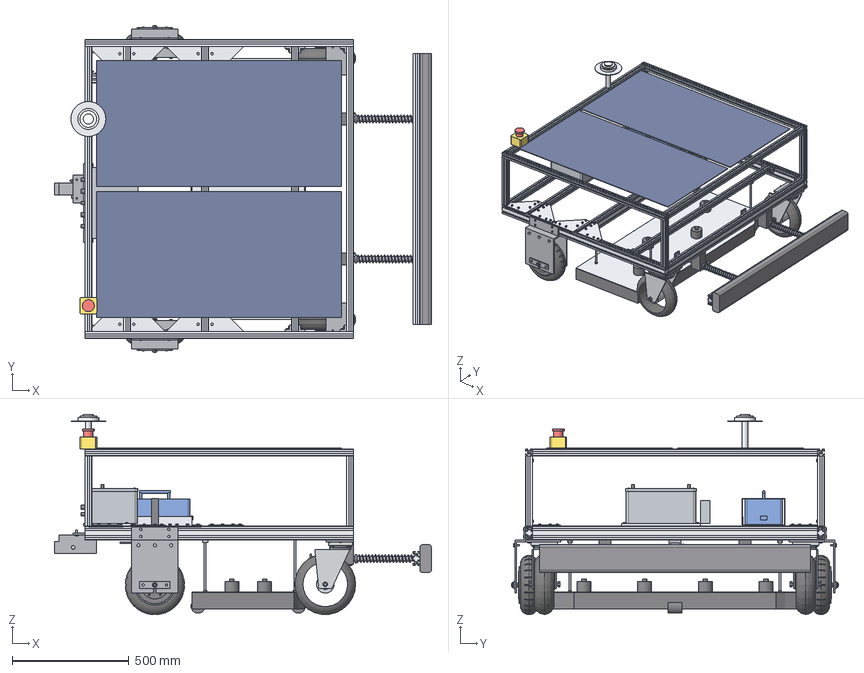
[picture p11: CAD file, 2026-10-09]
hardware/cad/exports/platform-v1-razor.step
1615.0 x 1402.0 x 858.0 mm
side_rail_L
side_rail_R
cross_member_1
cross_member_2
cross_member_3
cross_member_4
cross_member_5
battery_rail_1
battery_rail_2
tire_R x 2
hub_motor_R x 2
motor_cable_L
drive_fork_L
torque_arm_L
motor_cable_R
drive_fork_R
torque_arm_R
caster_tire_R x 2
caster_L
caster_plate_L
caster_R
caster_plate_R
razor_deck_plate
razor_deck_skirt
battery
battery_tray
battery_strap
electronics_box
electronics_lid
rear_hitch
hitch_pin
bumper_bar
bumper_foam
roof_post_1
roof_post_2
roof_post_3
roof_post_4
roof_rail_R
roof_rail_L
roof_rail_rear
roof_rail_front
gnss_mast
gnss_antenna
estop_base
estop_button
mppt_controller

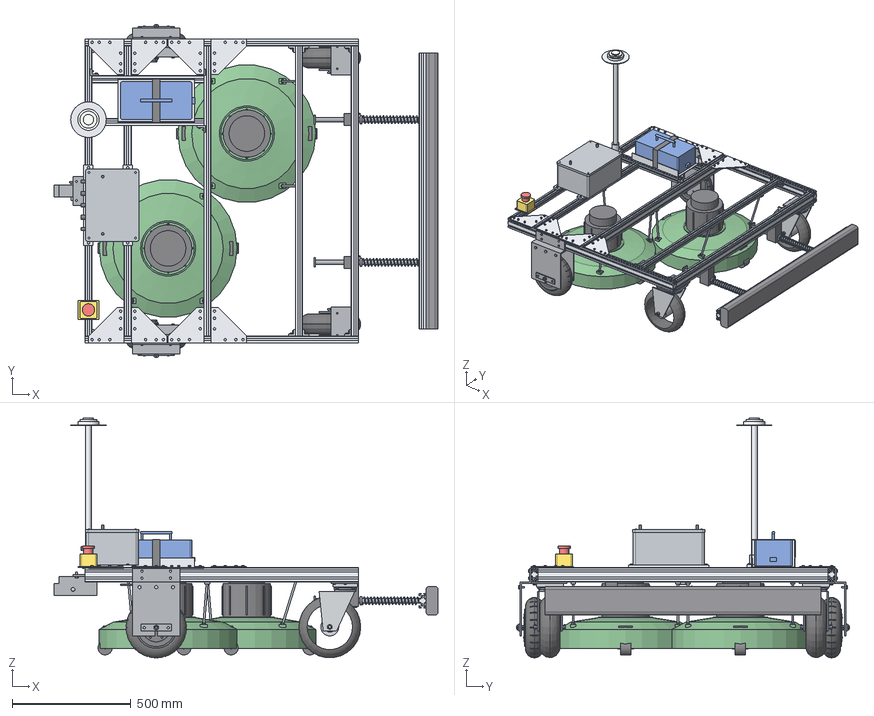
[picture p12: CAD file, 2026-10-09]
hardware/cad/exports/platform-v1-twin.step
1615.0 x 1402.0 x 1008.0 mm
side_rail_L
side_rail_R
cross_member_1
cross_member_2
cross_member_3
cross_member_4
cross_member_5
battery_rail_1
battery_rail_2
tire_R x 2
hub_motor_R x 2
motor_cable_L
drive_fork_L
torque_arm_L
motor_cable_R
drive_fork_R
torque_arm_R
caster_tire_R x 2
caster_L
caster_plate_L
caster_R
caster_plate_R
mower_deck_1
mower_deck_2_blade x 2
mower_deck_2_motor x 2
mower_deck_2
battery
battery_tray
battery_strap
electronics_box
electronics_lid
gnss_mast
gnss_antenna
estop_base
estop_button
rear_hitch
hitch_pin
bumper_bar
bumper_foam

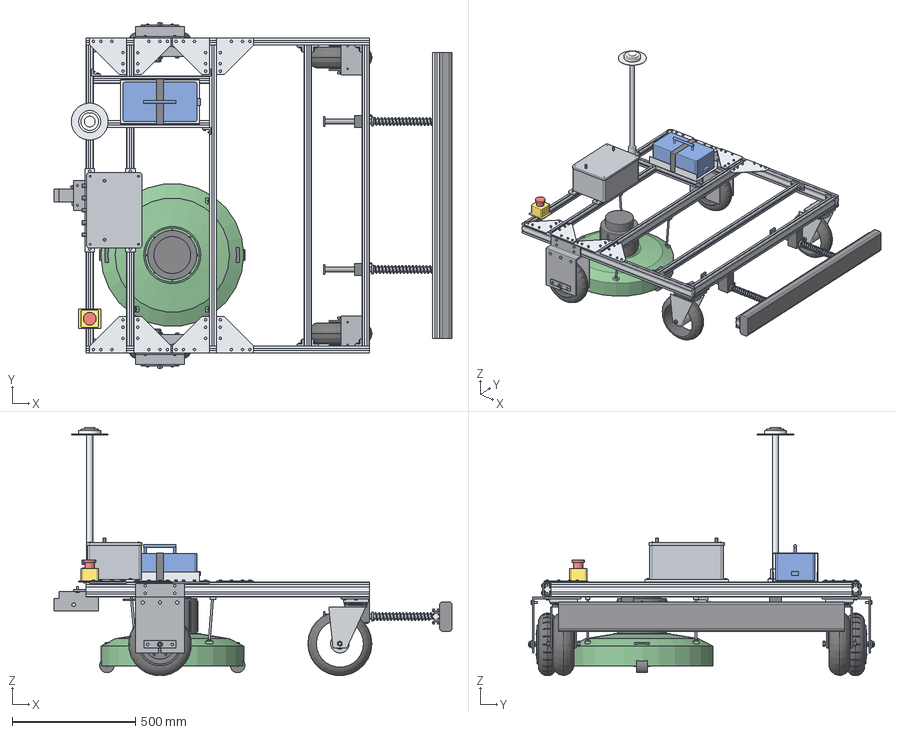
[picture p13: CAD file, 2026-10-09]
hardware/cad/exports/platform-v1-single.step
1615.0 x 1402.0 x 1008.0 mm
side_rail_L
side_rail_R
cross_member_1
cross_member_2
cross_member_3
cross_member_4
cross_member_5
battery_rail_1
battery_rail_2
tire_R x 2
hub_motor_R x 2
motor_cable_L
drive_fork_L
torque_arm_L
motor_cable_R
drive_fork_R
torque_arm_R
caster_tire_R x 2
caster_L
caster_plate_L
caster_R
caster_plate_R
mower_deck_1
mower_deck_1_blade
mower_deck_1_motor
battery
battery_tray
battery_strap
electronics_box
electronics_lid
gnss_mast
gnss_antenna
estop_base
estop_button
rear_hitch
hitch_pin
bumper_bar
bumper_foam

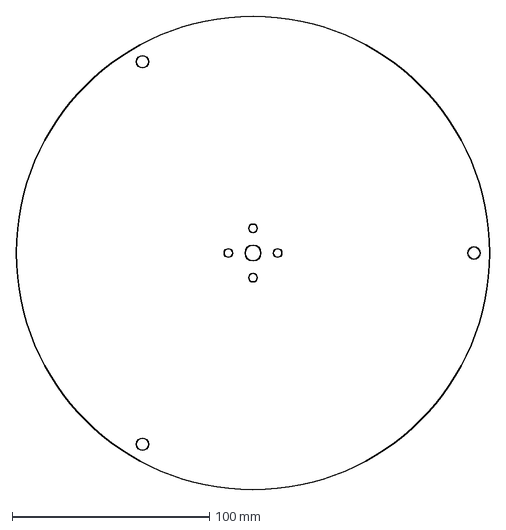
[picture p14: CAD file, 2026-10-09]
hardware/cad/exports/razor-disc.dxf
240.0 x 240.0 mm

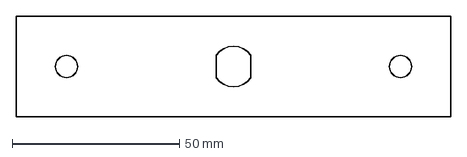
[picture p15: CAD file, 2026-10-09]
hardware/cad/exports/torque-arm.dxf
130.0 x 30.0 mm

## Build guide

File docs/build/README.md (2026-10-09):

# Build tutorial: Orbitist platform v1, one step at a time

This is the hands-on path from an empty bench to a mowing robot. Each step is a separate page with:

- **Buy:** the exact parts for that step, with links checked on the date shown at the top of the page, prices as seen that day, and the specification to check if a listing has changed.
- **Do:** the work, in order, with what "done" looks like.
- **Record:** measurements to write into [`measurements.md`](measurements.md). They feed `hardware/cad/params.py`, so the model, cutting files and reports regenerate from real parts.

Work one step at a time. Finish a step's **Done when** checklist before buying the next step's parts; several later purchases depend on numbers measured earlier (the battery size on the blade test, the plate DXFs on the motor axle and caster).

| Step | What | Spend (approx.) | Depends on | Status |
|---|---|---|---|---|
| [1](step-01-de-risk.md) | De-risking tests: one razor disc + one solar panel on the lawn, one hub motor + VESC on the bench, caster measurements | $450–600 | — | links checked (disc motor and panel links pending) |
| [2](step-02-rtk-base.md) | RTK base station and rover GPS; survey the base; map the lawns | $700–900 | — (parallel with 1) | links checked |
| [3](step-03-autopilot-bench.md) | Flight controller, radios, e-stop receiver on the bench; load our parameters and script | $350–400 | 2 (for GPS) | links checked |
| [4](step-04-frame.md) | Frame: extrusion, brackets, gussets, cut plates | ~$500 | 1 (axle and caster dimensions) | outline |
| [5](step-05-drive-modules.md) | Second motor and VESC, forks, torque arms; drive modules on the frame | ~$350 | 1, 4 | outline |
| [6](step-06-casters-bumper.md) | Casters on corner plates, sprung bumper with switches | ~$150 | 4 | outline |
| [7](step-07-electrical.md) | Battery, contactor, fuses, DC-DCs, MPPT, e-stop loop; commissioning tests | ~$600 | 1 (pack size), 5, 6 | outline |
| [8](step-08-autopilot-on-robot.md) | Autopilot on the robot, RC driving, steering tuning, first missions without blade | — | 3, 7 | outline |
| [9](step-09-deck.md) | Razor deck module: four discs, plate, skirt, hangers, interlocks, supervised daily mowing | ~$400 | 1, 8 | outline |
| [9b](step-09b-solar-roof.md) | Solar roof: posts, roof frame, panels, MPPT; antenna and e-stop move up | ~$400 | 4, 7 | outline |
| [10](step-10-phase-2.md) | Phase 2: companion computer, obstacle sensing, unsupervised operation (no dock needed) | ~$400 | 9, 9b | outline |

Steps marked *outline* list the specification and the work; their purchase links get added (and checked) when we reach them, because listings and prices move.

## Conventions

- Prices are US retail as seen on the date in each page's header, before tax and shipping. Nothing here is sponsored; links are to the page I verified, usually the manufacturer's.
- **Spec first, link second.** If a link is dead or the price has jumped, buy anything that meets the spec line next to it.
- Used and salvaged parts are fine wherever a line says so. The battery can be a healthy used e-bike pack. The farm's existing Ryobi mower is the catch-up mower; it is not modified.
- Safety-critical items (fuses rated for 58 V DC, the fail-safe e-stop parts, the contactor) are marked **safety** and should not be substituted with cheaper parts that don't meet the rating.

## What you'll have at the end of each step

1. Measured numbers that settle the drive motor, battery and plate drawings, and a working one-wheel drive on the bench.
2. A base station on a post with its position fixed to ~2 cm, and a map file of the real lawns.
3. The autopilot talking to the GPS, radios and e-stop receiver on the bench, running our configuration.
4. A rolling frame you can push around.
5. A frame that drives under radio control (no autopilot yet).
6. The robot stops when the bumper is pushed.
7. The complete power and safety system, tested item by item.
8. The robot drives a planned mission across the lawn without a blade.
9. The robot mows a lawn zone, supervised, and keeps mowing daily on solar.
10. Daily unsupervised mowing.

Reference documents: [design](../design/platform-v1.md) · [electrical](../../hardware/electrical/README.md) · [CAD](../../hardware/cad/README.md) · [RTK base guide](../guides/rtk-base-station.md) · [simulation](../../software/sim/README.md) · [confidence plan](../design/confidence-plan.md)

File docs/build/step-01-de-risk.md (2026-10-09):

# Step 1: De-risking tests

*Links and prices checked 2026-10-08; revised 2026-10-09 for the razor-disc deck and solar roof (D27, D28). Spend: about $450–600. Time: a weekend, plus waiting for shipping.*

**Goal:** measure the three things the rest of the design depends on before the main purchase: how much power one razor disc draws cutting the farm's grass (and what a solar panel yields flat on the roof), whether a cheap hub motor can run at mowing speed without overheating, and the exact dimensions of the motor and caster that the cut plates are drawn around. Everything bought here is used in the final robot.

## Buy

| ✓ | Item | Spec to check | Where | Price seen |
|---|---|---|---|---|
| ☐ | **One razor-disc cutting unit** | Brushless motor, 36 V class (24–36 V nominal, no-load 2,500–3,500 rpm), ≥ 100 W, with a matching BLDC driver that takes a PWM/enable signal (robot-mower blade-motor replacements and generic "36 V 350 W BLDC driver" boards both work); one disc cut from [`razor-disc.dxf`](../../hardware/cad/exports/razor-disc.dxf) (3 mm aluminium, SendCutSend or hand-cut) with **three standard robot-mower razor blades** and M6 shoulder screws; a motor hub/shaft adapter to suit the motor | Links to be checked when ordering; blades: any "Automower-compatible razor blades" pack (~$10 per 9) | $60–120 |
| ☐ | **One solar panel** | Semi-flexible, ~100–120 W, ~1.05 × 0.54 m, with bypass diodes; plus a 36 V-battery **boost MPPT** charge controller later (step 7) | Links to be checked when ordering | $90–150 |
| ☐ | **One 10" hub motor** | Brushless, gearless, **Hall sensors** (5 thin wires + 3 thick), pneumatic 10×2.5–3" tire, **axle with flats on both sides** (two dropouts), 36–48 V winding, 350–1000 W. A 48 V motor is fine on our 36 V pack: it just runs slower and makes more torque per amp, which suits mowing. Avoid *geared* motors unless the listing confirms **no freewheel clutch** (the robot brakes and holds position with the motors). | [Wheelway eBay store](https://www.ebay.com/str/wheelway) (10" scooter motors; ask the seller for the axle drawing), or AliExpress search "10 inch hub motor 36V hall sensor". A US-stock but pricier option: [VXB 10" hub motor kit](https://vxb.com/products/10-inch-wheel-hub-motor-assembly-delivering-badass) ($329; confirm axle type first). | $100–240 |
| ☐ | **One VESC controller** | VESC 6 hardware, ≥ 60 V input, Hall sensor port, PPM input, CAN. | [Flipsky 75100 Pro](https://flipsky.net/products/flipsky-75100-pro-with-aluminum-pcb-based-on-vesc-for-electric-skateboard-electric-scooter-ebike-speed-controller) ($89, 14–84 V, 100 A, Hall port, PPM/UART/CAN). Budget: the plain [Flipsky 75100](https://flipsky.net/products/flipsky-75100-75v-100a-single-esc-based-on-vesc-for-electric-skateboard-electric-scooter-ebike-speed-controller) ($65). Note Flipsky's warning: disable the phase filter in VESC Tool on firmware ≥ 5.3. | $65–89 |
| ☐ | **One 10" pneumatic swivel caster, plate mount** | ≥ 300 lb, plate ~4" × 4.5". | [Harbor Freight Haul-Master 10" pneumatic swivel caster, SKU 63799](https://www.harborfreight.com/10-in-pneumatic-swivel-caster-63799.html) ($19.99, 300 lb, bolt pattern 3" × 3-3/8"). | $20 |
| ☐ | **Bench power supply** | 0–60 V, ≥ 5 A, with **adjustable current limit** (constant-current mode). Used for every first power-up in this project. | [Vetco 60 V 5 A lab supply](https://vetco.net/products/vupn2187_60v_5a_adjustable_bench_top_lab_dc_power_supply) ($190; check stock). Cheaper generic 60 V 5 A units (~$70–100) are fine if they state CC mode. | $70–190 |
| ☐ | DC clamp meter (optional but useful) | Reads DC amps, ≥ 40 A | Any brand with "DC current" clamp (e.g. UNI-T UT210E class) | $30–60 |
| ☐ | 3-phase wiring bits | XT60 pair, 12 AWG silicone wire, JST-PH or the Hall connector your motor uses, crimper | Amazon / local | $20 |
| ☐ | Digital calipers (if the shop doesn't have them) | 150 mm | any | $15–25 |

Also needed, no purchase: a laptop with [VESC Tool](https://vesc-project.com/vesc_tool) (free), a bathroom scale, a stopwatch, a tape measure, something to load the motor (see T3), and the farm's existing Ryobi mower for the catch-up cut before the razor test.

## Do

### T1. One razor disc on the lawn, and one panel in the sun

1. **Build the test disc.** Cut the disc from `razor-disc.dxf`, fit three razor blades on M6 shoulder screws (they must swing freely), mount it on the motor with the hub adapter, mount the motor on a scrap board with a skirt of plywood around the disc for a guard, and set the blades 50 mm above the ground on two scrap wheels or runners. Wire the driver to the bench supply at 36 V, current limit 3 A at first.
2. **Spin-up check,** blades off: it should reach ~3,000 rpm; log the no-load current. Then with blades, in the air.
3. **Cut the lawn** (eye protection; nobody near): push the rig at walking pace over a lawn mown yesterday with the Ryobi, then over a strip left for a week. Log the current from the bench supply or clamp meter. Watts = 36 × amps. Expect 10–20 W on the daily strip; note what the weekly strip needs and whether the blades fold back.
4. **Stop time:** cut the power; time how long the disc spins. If more than 3 s, note it: the driver needs a brake input, or a small blade brake.
5. **Panel:** lay the panel flat in the sun at midday, short it through the clamp meter for the short-circuit current and read the open-circuit voltage; the product (× 0.75) approximates its real output flat on the roof. Repeat on a bright overcast day.

### T1b. The reel alternative (D31): one push reel mower on the same strips

Same afternoon, same lawn as T1. Borrow or buy one used 16–20" push reel mower (~$0–130).
1. Pick up sticks on a 100 m strip mown yesterday with the Ryobi, and leave a 100 m strip three days old.
2. Push the reel mower at 0.6 m/s (a slow walk; time 10 m in ~17 s) with a luggage scale hooked between your hand and the handle. Log the steady pull force on each strip.
3. Count jams and uncut stalks per 100 m. Note the cut quality against the razor-disc strip.
4. Weigh the mower, and the reel cartridge + wheels alone if you can strip it.

**Decision rule:** reel gang if pull force < 60 N per unit, fewer than one jam per 500 m after the stick pick-up, and a clean cut; otherwise razor discs. Either way, record the numbers in `measurements.md`.

### T3. One motor on the bench

1. **Measure the motor** before anything else: tire diameter and width, axle shoulder-to-shoulder, width across the flats, axle diameter, protrusion past each shoulder. These numbers set the fork plates and torque arms.
2. **Wire the VESC:** battery leads to the bench supply (set 36 V, current limit 2 A for the first power-up, raise later), three phase wires to the motor, the Hall connector to the sensor port. Install VESC Tool and connect over USB.
3. **Motor detection** (VESC Tool → FOC → Detect). Record flux linkage (→ torque constant), phase resistance, and the Hall table. Set **motor current max 50 A, battery current max 14 A**, timeout brake current 20 A, PPM timeout 100 ms.
4. **Low-speed check:** with the wheel off the ground, run at 45 rpm (our mowing speed) from VESC Tool's keyboard control. It should turn smoothly without cogging; that's what the Hall sensors are for.
5. **Thermal check:** load the motor to about 5 N·m for 30 minutes. Easiest rig: clamp the axle in a vise, wrap a strap around the tire with a known weight hanging from it (5 N·m ≈ 4 kg at the tire's 127 mm radius), and run at 45 rpm. Read the motor temperature every 5 minutes (VESC Tool shows it if the motor has a sensor; otherwise an IR thermometer on the can). **Pass:** under 70 °C and still rising slowly. **Fail:** climbs past 80 °C. A fail means we switch to a geared or wheelchair motor before buying the second one; the frame accepts either.
6. **Brake test:** spin the wheel to 45 rpm, then unplug the PPM signal (or stop sending it). The VESC must brake within its 100 ms timeout and hold the wheel.

### T4. Caster

Measure the top plate, bolt pattern and hole size, overall height, wheel diameter and width, and the swivel offset. Spin the swivel: it should be smooth with no lift.

## Record

Write everything into [`measurements.md`](measurements.md), then update `hardware/cad/params.py` and `drive_energy.py` and regenerate (`build.py`, `strength.py`, `drive_energy.py`). Commit the measurements and the regenerated exports together.

## Done when

- [ ] Disc cutting power and panel yield are measured numbers, not ranges; reel pull force and jam rate recorded (T1b).
- [ ] The motor ran 30 minutes at mowing load and stayed under 70 °C.
- [ ] The motor brakes and holds when the signal stops.
- [ ] `params.py` has the real axle, tire and caster dimensions, and the DXFs regenerated.
- [ ] Decision recorded in the [decision log](../decisions/README.md): drive motor type confirmed (or changed); pack size for step 7 (10 or 15 Ah); disc count (4, or 3 if power allows a bigger disc), or the reel gang instead (D31).

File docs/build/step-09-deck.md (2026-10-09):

# Step 9: Razor deck module and supervised mowing

*Outline. Links added when we reach it. Revised 2026-10-09 for the razor-disc deck (D27).*

## Buy (spec)

| Item | Spec | Qty |
|---|---|---|
| Disc motors + drivers | identical to step 1's | 3 more (4 total) |
| Discs | `razor-disc.dxf`, 3 mm aluminium | 3 more |
| Razor blades + shoulder screws | robot-mower razor blades; M6 × 10 shoulder screws | 12 + spares |
| Deck plate | 3 mm aluminium per CAD outline (DXF to be exported once step 1 fixes the motor hole pattern) | 1 |
| Skirt | 6 mm HDPE strip, 70 mm tall, bent/joined around the plate | ~3.2 m |
| Hangers | M8 threaded rod, nuts, slot-8 drop-in T-nuts | 4 sets |
| Anti-scalp rollers | 60 mm wide, Ø60 | 2 |
| Blade enable wiring | all four drivers' enable/PWM lines switched together by K5; 2-core shielded cable | — |

## Do

1. Drill the plate for the motors, bolt the motors on top, discs underneath, blades on; fit the skirt and rollers.
2. Hang the deck from the members at x = 215 and x = 600 on the four rods; set the blade height to 50 mm with the rods, level front-to-back and side-to-side.
3. Wire the drivers: 36 V from the fused motor bus; enable lines through K5 (the blade relay) so the Lua interlock and the hardware e-stop both control all four discs. Set each driver's speed to ~3,000 rpm.
4. Electrical README §8 steps 6 and 7: disc stop time on every e-stop path, bumper push at 0.6 m/s.
5. **Catch-up cut first:** mow every zone once with the Ryobi so the razors only see regrowth.
6. First supervised mow: a small open zone, wireless e-stop in hand, nobody else in the zone. Then the full zone list, daily.

## Done when

- [ ] All four discs stop within 3 s on every e-stop path; discs never run outside AUTO (`BLADE` named value in the logs).
- [ ] Two weeks of daily mowing with no uncut strips and the battery never below 30 % at dawn (solar keeping up).

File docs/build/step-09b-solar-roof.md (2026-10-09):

# Step 9b: Solar roof

*Outline. Links added when we reach it. See D28.*

## Buy (spec)

| Item | Spec | Qty |
|---|---|---|
| Solar panels | semi-flexible, ~100–120 W, ~1.05 × 0.54 m, bypass diodes (one bought in step 1) | 1 more |
| MPPT charge controller | **boost** type for a 36 V-class battery from ~18–36 V panel input (Genasun GVB-8 class), Li-ion/LiFePO4 profile to suit the pack | 1 |
| Roof extrusion | 30x30: 4 posts + 4 rails per the [cut list](../../hardware/cad/exports/cut-list.md); corner brackets | kit |
| Backing sheet | 1.5 mm aluminium or 3 mm twin-wall polycarbonate, frame size | 1 |
| Hinges + gas strut or prop | so the roof lifts for access to the battery and electronics | 2 + 1 |
| Panel fixing | VHB tape or edge clips, MC4 extension, gland into the enclosure | — |

## Do

1. Bolt the posts to the side rails at the corners, the roof rails on top; square it; fit the backing sheet.
2. Mount the panels, wire them in series (or parallel, to suit the MPPT's input range) to the MPPT; MPPT output to the battery through its own 15 A fuse.
3. Move the GNSS antenna onto the stub on the rear roof rail (ground-plane disc under it) and the e-stop beside it; re-run the GPS and e-stop checks.
4. Log a full sunny day parked: the pack should reach full by early afternoon.

## Done when

- [ ] Panel output at midday within 20 % of the step-1 measurement; MPPT charging at 36–42 V.
- [ ] Antenna still reaches RTK Fixed on the roof; e-stop reachable from behind.

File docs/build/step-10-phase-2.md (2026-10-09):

# Step 10: Phase 2, unsupervised-capable

*Outline. Designed after step 9 runs for a few weeks. With the solar roof there is no charging dock to build.*

- Raspberry Pi 5 companion (ROS 2): OAK-D Lite or radar for obstacle stops; speed-up to 1.0 m/s once obstacle sensing works (shorter mowing hours, more solar margin).
- Fixed cameras on the first polyculture beds and a weekly drone map: the sensing layer for v2.
- Optional: AprilTag-guided parking spot in full sun (ArduPilot Dock mode) so the robot always ends the day where it charges best.
- v2 design note: the 1-D bed gantry or cable robot for the test plot (D30), reusing the VESC drive, safety chain and RTK base.

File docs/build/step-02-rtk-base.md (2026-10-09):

# Step 2: RTK base station and lawn survey

*Links and prices checked 2026-10-08. Spend: about $700–900. Time: one afternoon to build, 24 h logging, a few days waiting for the position report, one afternoon walking the lawns.*

**Goal:** a permanent GPS base station on the farm with its position fixed to about 2 cm, a rover receiver that gets centimetre fixes from it, and a map of the real lawn edges. The base serves every robot you build later. Can run in parallel with step 1.

Full procedure: [RTK base station guide](../guides/rtk-base-station.md).

## Buy

| ✓ | Item | Spec to check | Where | Price seen |
|---|---|---|---|---|
| ☐ | **2× u-blox ZED-F9P receiver boards** (base + rover) | ZED-F9P, USB and UART2 broken out; an XBee socket is handy but not required (we use SiK radios) | [ArduSimple simpleRTK2B Budget](https://www.ardusimple.com/product/simplertk2b/) (€172 each, ships from Spain) | 2 × ~$190 |
| ☐ | **Base antenna** | Multiband (L1/L2) survey-style antenna with a ground plane, 5/8" mount thread, IP66+ | [ArduSimple Budget Survey Multiband GNSS Antenna](https://www.ardusimple.com/product/survey-gnss-multiband-antenna/) (€89, TNC + 2.5 m SMA pigtail, IP66) | ~$100 |
| ☐ | **Rover antenna** | Multiband, magnetic or screw mount, SMA, 5 m cable | [u-blox ANN-MB-00 at ArduSimple](https://www.ardusimple.com/product/u-blox-gnss-multiband-antenna-ann-mb-00-ip67-bulk/) (€53.80) or [SparkFun GPS-15192](https://www.sparkfun.com/products/15192) ($109.95, same antenna) | $60–110 |
| ☐ | **Radio pair for corrections** (base → rover) | 915 MHz, transparent serial, ≥ 100 mW | [Holybro SiK Telemetry Radio V3, 915 MHz 100 mW](https://holybro.com/products/sik-telemetry-radio-v3) ($58.99; confirm the listing is the pair) | $59 |
| ☐ | **Raspberry Pi** for the base (logs the 24 h survey; later an NTRIP caster) | Pi 4 (2 GB is plenty) or Pi 5, with power supply and a 32 GB microSD | [Raspberry Pi 4 Model B](https://www.raspberrypi.com/products/raspberry-pi-4-model-b/) via an approved reseller | $60–90 |
| ☐ | Mast and box | 1–1.5" galvanised pipe or a wall bracket, a weatherproof box for the F9P + Pi (IP65, ~20 × 15 × 10 cm), a 5 V supply, SMA bulkhead and 5 m low-loss SMA cable if the antenna pigtail is too short | hardware store / Amazon | $60–100 |
| ☐ | For the survey cart | A wheelbarrow or garden cart, a USB power bank, your laptop | — | $0 |

**Why ArduSimple over SparkFun for the boards:** the Budget board has UART2 on a header with the right default (38400 baud, RTCM in), so the radio plugs straight in on the rover with no configuration. The configuration script in `software/base-station/` works with any ZED-F9P board over USB.

## Do

1. **Site the base** (guide §2): clear sky, rigid mount, power, as central as practical. Mount the survey antenna on the mast, run its cable into the box.
2. **Pi setup** (guide §4): install Raspberry Pi OS, `rtklib`, clone the repo, create the venv, confirm the F9P shows as `/dev/ttyACM0`.
3. **Radios** (guide §5): configure both SiK radios to 38400 baud, MAVLink framing **off**, a NETID of your choosing. Label them BASE and ROVER.
4. **Log 24 h** (guide §6): `configure_f9p_base.py raw-log`, then `str2str` for a day. Convert with `convbin` and submit to CSRS-PPP. While waiting, run **survey-in** mode so you can test the rover.
5. **Rover on the cart:** rover F9P on USB to the laptop, ANN-MB antenna on the cart on a metal plate ≥ 10 cm, ROVER radio into the F9P's UART2 header. Confirm **RTK Fixed** in u-center or with `configure_f9p_base.py PORT status`.
6. **Walk the lawns.** Push the cart along every lawn edge, around every tree and bed, and along the paths between zones, logging positions (u-center or a short Python script using `pyubx2`). Note gate widths and anything under tree cover where the fix drops to Float.
7. **When the PPP report arrives:** set the base to `fixed` with the reported latitude, longitude and ellipsoidal height; record them in `docs/guides/base-station-position.md`. **Re-walk the edges** if you mapped them while the base was in survey-in mode (the map shifts by the survey-in error).
8. **Make the lawn file:** convert the walked polygons to a `software/sim/lawns/<farm>.json` (metres east/north of an origin; the file format is in `sample-farm.json`). Run `coverage.py` on it: you now have real missions, fences and mowing-time estimates for your farm.

## Record

- The base position and antenna details in `docs/guides/base-station-position.md`.
- The lawn file, committed to `software/sim/lawns/`.
- Where RTK dropped to Float during the walk (tree cover): a note in the lawn file's `_comment`.

## Done when

- [ ] Base runs `fixed` mode from the PPP position and resumes by itself after a power cut.
- [ ] Rover reaches RTK Fixed within 2 minutes under open sky and repeats a marked point to ±2 cm an hour apart.
- [ ] `coverage.py lawns/<farm>.json` runs and produces a plan for every zone.

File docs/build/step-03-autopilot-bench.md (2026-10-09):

# Step 3: Autopilot, radios and e-stop receiver on the bench

*Links and prices checked 2026-10-08. Spend: about $350–400. Time: an evening or two.*

**Goal:** the flight controller running ArduPilot Rover with our parameter file and the blade-interlock script, talking to the rover GPS, both radios, the RC transmitter and the wireless e-stop receiver, all on the bench. By the end you can arm it, see RTK Fixed, trip the e-stop and watch the script disarm. Nothing moves yet.

## Buy

| ✓ | Item | Spec to check | Where | Price seen |
|---|---|---|---|---|
| ☐ | **Flight controller** | ArduPilot-supported H7 board with ≥ 8 PWM outputs, 2 GPS ports, 2 telemetry ports, SD card. With a **12S-rated power module** (our bus is 36 V nominal, 42 V max). | [Holybro Pixhawk 6C Mini, Model-A revision, with PM02 V3](https://holybro.com/products/pixhawk-6c-mini) ($149.98 with the power module) | $150 |
| ☐ | **RC transmitter** | ExpressLRS 2.4 GHz, ≥ 2 two-position switches (arm, e-stop RUN) and one 3-position (mode), EdgeTX | [RadioMaster Pocket, ELRS, FCC](https://www.radiomasterrc.com/products/pocket-radio-controller-m2) ($71.50) plus 2 × 18650 cells. A larger radio (TX12, Boxer) is fine too. | $72 + cells |
| ☐ | **Receiver for driving** (to the flight controller) | ELRS 2.4 GHz, CRSF serial output | [RadioMaster RP3 V2 ExpressLRS nano receiver, FCC](https://www.radiomasterrc.com/products/rp3-expresslrs-2-4ghz-nano-receiver) ($19.99) | $20 |
| ☐ | **Receiver for the wireless e-stop** (separate from the above) | ELRS 2.4 GHz with **PWM outputs** and configurable failsafe (set to **No Pulses**) | [RadioMaster ER6 6-channel ELRS PWM receiver](https://motionrc.com/products/radiomaster-er6-6-channel-elrs-pwm-receiver-hp0157-rx-er6) ($27.99) | $28 |
| ☐ | **E-stop receiver microcontroller** | Arduino Nano (ATmega328P, 5 V) + a 1-channel 5 V relay module (active-HIGH input) | Any Nano clone with the Optiboot bootloader; firmware in [`software/estop_receiver`](../../software/estop_receiver/README.md) | $10–15 |
| ☐ | **Telemetry radio pair** (robot ↔ laptop) | 915 MHz SiK, second pair, **different NETID** from the RTK pair | [Holybro SiK Telemetry Radio V3, 915 MHz](https://holybro.com/products/sik-telemetry-radio-v3) ($58.99) | $59 |
| ☐ | Bench odds and ends | 5 V 3 A USB supply for the bench (the PM02 needs the battery bus; on the bench power the FC from USB), JST-GH cable kit (usually included with the Pixhawk), microSD card ≥ 8 GB, a few 2.54 mm servo leads | — | $20 |

The rover ZED-F9P and its antenna come from step 2.

## Do

1. **Flash ArduPilot Rover 4.6.x** onto the Pixhawk with Mission Planner (Setup → Install Firmware → Rover). Create the SD card.
2. **Load our configuration:** Config → Full Parameter List → Load from file → [`software/ardupilot/params/orbitist-v1.param`](../../software/ardupilot/params/orbitist-v1.param) → Write Params → reboot. Copy [`blade_interlock.lua`](../../software/ardupilot/scripts/blade_interlock.lua) to the SD card under `APM/scripts/`, reboot, and confirm "Blade interlock loaded" in the Messages tab. The `BLD_*` parameters now exist.
3. **GPS:** rover F9P to the GPS1 port (UART1 on the F9P), antenna on a metal plate outdoors or on a windowsill. With the base running, the HUD should show *rtk Fixed* (GPS status 6). ROVER SiK radio into the F9P's UART2 header as in step 2.
4. **RC:** flash the Pocket and both receivers to the same ExpressLRS version and bind phrase (ELRS configurator, Wi-Fi). RP3 to the Pixhawk's RC IN (CRSF). In Mission Planner's Radio Calibration, check all channels move, map channel 7 to a two-position switch (`RC7_OPTION 153` = arm/disarm) and channel 8 to a three-position switch (mode: Manual / Hold / Auto).
5. **Wireless e-stop:** ER6 channel 1 ← a second two-position switch on the Pocket ("RUN"). In the ELRS Lua on the transmitter, set the ER6's **failsafe to No Pulses**. Flash the Nano with `software/estop_receiver` (`arduino-cli compile … && arduino-cli upload …`). Wire ER6 ch1 signal → Nano D2, Nano D7 → relay IN, 5 V and GND to all three. Run the acceptance test in that README: the relay must drop for a switch-down, transmitter off, out of range, unplugged signal, and must stay off for ~0.2 s after a power cycle.
6. **E-stop input to the autopilot:** on the bench, wire the relay's NO contact in series with 3.3 V to a spare AUX pin configured as GPIO, and set `BLD_ESTOP_SRC 1`, `BLD_ESTOP_PIN <that pin>`. Arm with the switch (Hold mode); flip RUN down; the script must report "ESTOP loop open: disarmed".
7. **Telemetry:** second SiK pair between TELEM1 and the laptop; Mission Planner connects over it at 57600.
8. **Simulation handshake:** run `software/sim/run_sitl.py` once more on the real lawn file from step 2 so the missions you'll load later have already passed the acceptance tests.

## Record

- The AUX pin used for ESTOP_OK and the relay output pin for the blade (`RELAY1_PIN`) in the parameter file; commit it.
- ELRS version and bind phrase (in a private note, not the repo).

## Done when

- [ ] HUD shows rtk Fixed, both radios link, all RC channels calibrated.
- [ ] Arm/disarm works only from the switch.
- [ ] The wireless e-stop passes all five acceptance tests, and tripping it disarms the autopilot via the script.
- [ ] `orbitist-v1.param` in the repo matches what is on the flight controller.

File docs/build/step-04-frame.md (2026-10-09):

# Step 4: Frame

*Outline. Purchase links get added and checked when step 1 is done (the plate drawings depend on the measured motor axle and caster).*

**Goal:** the bare frame, square and bolted, with gussets, the plates cut, standing on blocks.

## Buy (spec)

| Item | Spec | Qty | Notes |
|---|---|---|---|
| 30×30 T-slot extrusion, slot 8 | 6-series (Misumi HFS6-3030 class), cut to length | per [cut list](../../hardware/cad/exports/cut-list.md) | Misumi US cuts to length for free on configurable part numbers (HFS6-3030-[length]); their US pages were not reachable from here to verify pricing, so get a quote |
| 30×60 T-slot extrusion, slot 8 | HFS6-3060 class | per cut list | same |
| Cast inside corner brackets, 30-series | with M6 bolts and T-nuts | ~24 | 2 per cross-member end + battery rails |
| Slot-8 T-nuts and M6/M8 bolts | stainless, assorted 12–20 mm | 100+ | buy a kit |
| Cut plates | from [`hardware/cad/exports/*.dxf`](../../hardware/cad/exports): fork side plates (6 mm steel ×4), fork top plates (8 mm ×2), saddle tabs, torque arms (5 mm ×4), gussets (5 mm aluminium ×8), caster plates (8 mm steel ×2) | — | Upload the DXFs to SendCutSend or a local laser/water-jet shop. Order **only after** step 1's measurements are in `params.py` |
| Chop-saw blade for aluminium (if cutting at home) | non-ferrous, negative rake | 1 | or have Misumi cut everything |

## Do

1. Lay out the side rails and cross members per the [top view](../../hardware/cad/exports/platform-v1-single-top.png); member positions are in `params.py` (`cross_member_x`).
2. Square the frame on a flat floor (equal diagonals), fit corner brackets, then the gussets at the two drive-adjacent members, torque the bolts and mark them with paint.
3. Fit the battery support rails and the saddle-tab fork top plates (without motors) to check the plate fit against the real extrusion.
4. Deburr every cut; tap the caster plates M8.

## Done when

- [ ] Diagonals equal within 2 mm; all joints bolted, torque-striped.
- [ ] Every cut plate test-fits its location.

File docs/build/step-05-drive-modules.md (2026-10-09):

# Step 5: Drive modules

*Outline. Links added when we reach it.*

**Goal:** both wheels on the frame, each driven by its own VESC, driving under radio control from the transmitter through the Pixhawk (Manual mode).

## Buy (spec)

| Item | Spec | Qty |
|---|---|---|
| Second hub motor | identical listing to step 1's | 1 |
| Second VESC | identical to step 1's | 1 |
| Torque-arm and fork fasteners | M8 × 20 class 8.8 (fork plates), M6 × 16 (torque arms, saddle tabs), nyloc nuts, torque washers | kit |
| Phase and Hall extension leads | 12 AWG silicone, 3 m; 6-pin Hall extension | 2 sets |
| 36 V test pack or bench supply at 36 V, 10 A | the real battery arrives in step 7; a used e-bike pack or the bench supply (current-limited) is enough to drive on blocks | — |

## Do

1. Assemble each fork: side plates, top plate, saddle tabs; slide the axle in with the flats seated, fit the torque arm on the outboard plate, nuts torqued.
2. Bolt the forks under the side rails at x = 0 (into the bottom slot and both side slots).
3. Mount both VESCs in the electronics position (the enclosure comes in step 7; a temporary plate is fine), set them up identically to step 1 (motor detection again for the second motor), set the PPM app to **PID speed** mode with ~2 m/s full scale.
4. Pixhawk outputs 1 and 3 → VESC PPM inputs (through the K4 relay later; direct for now). Set VESC PPM centre/endpoints from the Pixhawk's output range.
5. On blocks: Manual mode, arm, throttle: both wheels turn the same direction at the same speed, steering turns them opposite. Fix any reversed motor in VESC Tool (invert motor direction), never by swapping phase wires at random.
6. On the ground, in the barn: drive straight, pivot, stop. Check the `MOT_SAFE_DISARM` behaviour: disarming stops the pulses and the VESCs brake.

## Done when

- [ ] Robot drives straight at 0.6 m/s under RC with matched wheel speeds.
- [ ] Disarm brakes both wheels within 0.2 s.

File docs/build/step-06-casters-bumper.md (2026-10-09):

# Step 6: Casters and bumper

*Outline. Links added when we reach it.*

## Buy (spec)

| Item | Spec | Qty |
|---|---|---|
| Second caster | identical to step 1's | 1 |
| Caster spacers | per the thickness in `report.md` ("Needs a N mm spacer"), steel or aluminium | 2 |
| Bumper bar | 30×60 extrusion offcut (length per CAD), or 25×50 aluminium tube | 1 |
| Bumper arms | Ø20 steel or aluminium tube, 2 pcs | 2 |
| Guide blocks | UHMW or Delrin block 60×50×50 bored Ø21, or 3D-printed PETG | 2 |
| Return springs | compression, ~Ø30 OD, free length per CAD, 2–4 N/mm | 2 |
| Microswitches | roller-lever, **NC contact**, IP67 if available | 2 |
| Closed-cell foam | 50 mm, bar length | 1 |

## Do

1. Bolt the caster plates to the front corners (rail bottom slot + front member bottom slot), then the casters with spacers, M8 from below.
2. Make the guide blocks, bolt them under the front member at y = ±300, fit the arms, collars, springs and the bar.
3. Mount the switches on the guide blocks so the collar presses the lever after ~8 mm of travel; wire them in series (NC) on a lead to the future e-stop loop.
4. Push test: the bar must move freely, return fully, and both switches open within the first 10 mm.

## Done when

- [ ] Robot rolls on all four wheels, casters swivel freely through 360° without touching the bumper hardware.
- [ ] Bumper trips both switches and returns.

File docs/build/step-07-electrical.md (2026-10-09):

# Step 7: Power and safety electrical

*Outline. Links added when we reach it. Battery size is decided by step 1's blade test.*

Design and parts list: [`hardware/electrical/README.md`](../../hardware/electrical/README.md). Everything marked **safety** must meet the stated rating.

## Buy (spec)

| Item | Spec | Qty |
|---|---|---|
| Battery | 36 V-class pack (10S Li-ion or 12S LiFePO4), **size per step 1 decision**, BMS ≥ 30 A continuous, with charger | 1 (or 2) |
| **safety** Main fuse + holder | MRBF or Class T, 40 A, ≥ 58 V DC | 1 |
| Battery disconnect switch | ≥ 48 V DC, ≥ 50 A | 1 |
| **safety** Main contactor | 12 V coil, ≥ 60 V DC, ≥ 50 A continuous (Albright SW60 / TE LEV100 class) | 1 |
| Precharge relay + resistor | 12 V automotive relay; 47 Ω 10 W wirewound | 1 + 1 |
| Timer relay modules | 12 V on-delay (1.5 s) and off-delay (1.0 s) | 1 + 1 |
| Signal relay | 12 V DPDT, gold contacts (K4) | 1 |
| Blade relay | per the T1 bench test (small relay or DC contactor) | 1 |
| DC-DC converters | 36→12 V 10 A and 36→5 V 5 A, input ≥ 60 V | 1 + 1 |
| **safety** Fuse block and fuses | 58 V DC rated, 2–25 A assortment | 1 |
| E-stop | 22 mm mushroom, twist-release, NC block | 1 |
| Optocoupler module | 12 V in → 3.3 V out (ESTOP_OK) | 1 |
| Enclosure | IP65 polycarbonate ~300×220×150, cable glands, DIN rail | 1 |
| Wire and connectors | 10/12 AWG silicone, XT90s, ferrules, heat-shrink, labels | kit |

## Do

Follow the electrical README: §1 power distribution, §2 safety chain, §3 signal wiring, then **§8 commissioning tests in order**, wheels off the ground and no blade.

## Done when

- [ ] All eight commissioning tests pass and are logged in the electrical README's test record.

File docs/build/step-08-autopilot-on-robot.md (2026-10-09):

# Step 8: Autopilot on the robot, first missions (no blade)

*Outline. No purchases beyond step 3.*

## Do

1. Move the bench setup (step 3) into the enclosure: Pixhawk, PM02 on the main bus, RP3, telemetry radio, Nano + relay, F9P with the RTK radio; GNSS antenna on the mast with its ground plane.
2. Confirm `orbitist-v1.param` is loaded and the ESTOP_OK and blade relay pins are set.
3. Compass and accelerometer calibration away from the barn; check heading against a known bearing. If heading is noisy near the motors, this is where the second F9P for GPS-yaw gets added.
4. **Steering and speed tuning** per the ArduPilot Rover tuning guide: `CRUISE_THROTTLE` so 0.6 m/s is reached, then `ATC_STR_RAT_*`, `ATC_SPEED_*`, `NAVL1`/`PSC` as needed. Record the values in the parameter file.
5. Load the real lawn's fence and a short mission from `coverage.py`; run it in Auto in the open, supervised, with the wireless e-stop in hand. Then a full zone.
6. Measure path-tracking error from the log (`mavlogdump` or Mission Planner's log viewer); set the planner's overlap accordingly.

## Done when

- [ ] A full zone mission completes without intervention; tracking p95 ≤ 10 cm.
- [ ] All failsafes re-tested on the lawn: RC off, e-stop, GPS antenna unplugged, fence breach by driving it in Manual.

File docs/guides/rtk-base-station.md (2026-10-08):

# Guide: setting up the farm RTK base station

**Goal:** a permanent GPS base station that sends centimetre-level corrections to the robot (and any future robot) over a 915 MHz radio, with its own position pinned down accurately enough that lawn maps never shift.

**Time:** about 2 hours of hands-on work, plus 24 hours of unattended logging and 1–3 days waiting for the position result.
**Do it before the ground freezes:** the mast is easier to mount now, and you'll want corrections working to map the lawn edges this fall.

---

## 1. What you need

| Item | Notes |
|---|---|
| u-blox ZED-F9P board | ArduSimple simpleRTK2B or SparkFun GPS-RTK2 class. An XBee-style socket makes the radio plug-in. |
| Multiband (L1/L2) GNSS antenna + ground plane | Survey-style antenna if budget allows, otherwise u-blox ANN-MB on a ≥ 10 cm metal plate |
| Antenna cable | SMA, low-loss (LMR-195/240 class). Keep it under ~10 m. |
| 915 MHz radio pair | SiK-class (e.g. Holybro SiK V3) or XBee-socket radios that match the F9P board. One end at the base, one on the robot. **Separate from the telemetry radio pair.** |
| Raspberry Pi | Pi 4 / Pi 5 / Zero 2 W with Raspberry Pi OS. Logs raw data for the position survey and can later serve corrections over the network. A laptop can stand in for the 24 h log. |
| Mast + mounts | Rigid pole (e.g. 1"–1.5" galvanised pipe) with an antenna mount, a weatherproof box for the F9P + Pi, and a 5 V power supply |
| Optional | Surge/lightning arrestor and grounding for a roof mount |

## 2. Choose the site

- **Clear sky:** no trees or buildings above ~15° elevation in any direction. Open-sky farms are ideal.
- **Rigid and permanent:** the antenna must not move by even a centimetre after its position is measured. Bolt the mast to a building or set it in concrete. No guy wires that sway, and no fence posts that heave with frost.
- **Away from reflectors:** keep it ≥ 1 m above a metal roof and away from tall metal walls.
- **Power and radio line of sight:** a building with power. Mount the 915 MHz radio antenna as high as practical so it can see all the lawns. SiK radios typically reach 1+ km over open ground.
- **Central** to the lawns if possible. Accuracy degrades by ~1 mm per km from the base, so it's irrelevant at farm scale, but radio range isn't.

Mark the antenna's exact mounting point. If it's ever removed, it must go back in the same place, or the position must be measured again.

## 3. Wire it up

```
 [GNSS antenna] ── SMA cable ── [ZED-F9P] ──USB── [Raspberry Pi] ── 5 V supply
                                    │
                                 UART2 (38400 baud, RTCM3 out)
                                    │
                             [915 MHz radio, base end]  ·····air·····  [radio, robot end] ── rover F9P UART2
```

- On ArduSimple boards, the radio plugs into the XBee socket, which is already connected to UART2.
- On other boards, wire F9P **UART2 TX → radio RX**, plus GND and power (check the radio's voltage).

## 4. Set up the Raspberry Pi

```bash
sudo apt update && sudo apt install -y rtklib python3-venv
git clone https://github.com/Orbitist/orbitist-robot.git
cd orbitist-robot/software/base-station
python3 -m venv .venv && .venv/bin/pip install -r requirements.txt
ls /dev/ttyACM*        # the F9P shows up as /dev/ttyACM0 over USB
```

`rtklib` provides `str2str` (logging and streaming) and `convbin` (format conversion). If the Debian package's `convbin` mishandles F9P data, build the [rtklibexplorer "demo5"](https://github.com/rtklibexplorer/RTKLIB) version instead.

## 5. Configure the radios (once)

Both radios in a pair must match. For SiK radios, connect each one to a computer by USB and use a serial terminal. On a Mac, run `screen /dev/cu.usbserial-XXXX 57600` (57600 is the factory default speed). Type `+++` and wait for `OK`, then:

```
ATS1=38      # serial speed 38400, matching F9P UART2
ATS2=64      # air data rate 64 kbps
ATS3=37      # NETID: any number, but different from the telemetry radio pair
ATS5=0       # ECC off
ATS6=0       # MAVLink framing OFF: corrections are raw RTCM, not MAVLink
AT&W         # save
ATZ          # reboot
```

## 6. Measure the base position (24 h log → PPP)

The base needs to know exactly where its antenna is. The free **Canadian CSRS-PPP service** works anywhere in the world, including the US. It processes 24 h of raw data into a position good to about 1–2 cm.

```bash
# 1. Turn on raw measurement output
.venv/bin/python configure_f9p_base.py /dev/ttyACM0 raw-log

# 2. Log for at least 24 hours (runs unattended; use tmux or nohup so it survives logout)
str2str -in serial://ttyACM0:115200 -out file://base_%Y%m%d_%h%M.ubx::S=24

# 3. Convert to RINEX
convbin -r ubx -v 3.04 -od -os -oi -ot base_*.ubx
```

4. Create a free account at [CSRS-PPP](https://webapp.csrs-scrs.nrcan-rncan.gc.ca/geod/tools-outils/ppp.php). Upload the `.obs` file and select **Static** processing and **ITRF** as the reference frame. Results arrive by email, usually within a few hours. Re-submit after ~2 weeks if you want the "final" orbits; the difference is usually millimetres.
5. From the results, record the **latitude, longitude, and ellipsoidal height** (*not* orthometric/sea-level height). Save them in [`base-station-position.md`](#8-record-the-position) along with the date and antenna type.

*Alternative:* NOAA [OPUS](https://geodesy.noaa.gov/OPUS/) accepts 2–48 h of dual-frequency GPS data and returns NAD83 coordinates. It can be fussier about F9P data, so try it only if CSRS-PPP isn't an option.

## 7. Start sending corrections

**Normal operation, with the PPP position known:**

```bash
.venv/bin/python configure_f9p_base.py /dev/ttyACM0 fixed --lat 42.1234567890 --lon -76.1234567890 --height 312.345
.venv/bin/python configure_f9p_base.py /dev/ttyACM0 status
```

The settings are saved to flash, so the base resumes sending corrections by itself after a power cut. The Pi isn't needed for that.

**Quick start while waiting for PPP results:**

```bash
.venv/bin/python configure_f9p_base.py /dev/ttyACM0 survey-in --minutes 60 --acc-m 2.0
```

Survey-in averages the base's own position, which is only accurate to ~1–2 m. The robot still gets centimetre-precise positions *relative to the base*, but all maps would shift by up to ~2 m when you switch to the PPP position later. So **use survey-in only for testing, and wait for the PPP position before recording lawn boundaries.** If you must map early, record the surveyed-in position (from `status`) and keep using it as the `fixed` position permanently. Consistency matters more than absolute accuracy for mowing.

## 8. Record the position

Create `docs/guides/base-station-position.md` (in git) with:

```
Base station: <location description, e.g. "north gable of the barn, mast at NE corner">
Antenna: <make/model>, mounted <date>
Position (ITRF2020, epoch <date>): lat <...>, lon <...>, ellipsoidal height <...> m
Source: CSRS-PPP, <n> h log, <date>, reported 95% accuracy <...>
```

If the antenna is ever moved or replaced, measure the position again and update this file. Lawn maps and fences are only valid against this one position.

## 9. Robot side

- The rover F9P connects to the flight controller's GPS1 port. ArduPilot configures it automatically (`GPS1_TYPE = 1`, `GPS_AUTO_CONFIG = 1`).
- The robot-end radio feeds the **rover F9P's UART2**, which accepts RTCM3 at 38400 baud by factory default. No configuration and no ArduPilot "GPS inject" needed.
- In Mission Planner or QGroundControl, the GPS status should go **3D Fix → RTK Float → RTK Fixed** within a minute or two under open sky. ArduPilot reports this as GPS status 6 (RTK Fixed).

**Acceptance test:** put the rover antenna on a fixed point, such as a nail in a fence post, and record the position. Move away, come back an hour later, and check that it reads within **±2 cm**.

## 10. Later: corrections over the network (NTRIP)

Once the farm network reaches the lawns, the Pi can also publish corrections as an NTRIP caster with `str2str`. Robots with Wi-Fi or LTE, a tractor's guidance system, or survey gear can then use the same base. For example:

```bash
str2str -in serial://ttyACM0:115200 -out ntripc://:password@:2101/FARM
```

That requires the F9P's RTCM output on USB as well as UART2. This step is optional; the radio link is all phase 1 needs.

## Troubleshooting

| Symptom | Check |
|---|---|
| Rover never reaches RTK Float | Radio link LEDs, matching NETID and speeds, `ATS6=0` (MAVLink framing off), and TX → RX wiring |
| Float but never Fixed | Sky view at the rover (trees), the antenna ground plane, and the base position actually being set (`status`) |
| Positions jump by ~1 m after reconfiguring | The base position changed (e.g. switching from survey-in to fixed). Expected; re-map or keep one position. |
| CSRS-PPP rejects the file | Log was too short, or the RINEX is missing observation types. Try the demo5 `convbin`. |

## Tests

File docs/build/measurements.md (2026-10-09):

# Measurements record

Fill these in as parts arrive. Each entry names the `params.py` field it feeds; after updating the
field, run `build.py`, `strength.py` and `drive_energy.py` in `hardware/cad/` and commit the regenerated
exports with the measurement.

## Hub motor (step 1)

| Measurement | Value | `params.py` field |
|---|---|---|
| Listing / model | | (note in commit) |
| Tire outside diameter (inflated, mm) | | `wheel_diameter` |
| Tire width (mm) | | `tire_width` |
| Motor can diameter (mm) | | `hub_diameter` |
| Axle: shoulder-to-shoulder (mm) | | `dropout_spacing` |
| Axle: width across flats (mm) | | `axle_flats` |
| Axle: diameter (mm) | | (strength.py `AXLE_D`) |
| Axle: length past each shoulder (mm) | | (check vs fork plate + torque arm + nut) |
| Flats on both ends? | yes / no | (single-sided needs a different fork) |
| Hall connector type, phase wire gauge | | — |
| Mass with tire (kg) | | `masses["hub_motor"]` |
| VESC detection: flux linkage / Kt (N·m/A) | | `drive_energy.KT` |
| VESC detection: phase resistance (Ω) | | `drive_energy.R_PHASE` |
| Bench: 30 min at ~5 N·m, can temperature (°C) | | — (pass if < 70 °C) |
| Bench: timeout-brake stop from 0.6 m/s equivalent | | `strength.BRAKE_DECEL` |

## Caster (step 1)

| Measurement | Value | `params.py` field |
|---|---|---|
| Wheel outside diameter (mm) | | `caster_wheel_diameter` |
| Wheel width (mm) | | `caster_wheel_width` |
| Swivel offset, pivot to axle (mm) | | `caster_trail` |
| Height, ground to top of plate (mm) | | `caster_height` |
| Top plate size (mm × mm) | | `caster_plate` |
| Bolt pattern (mm × mm) and hole diameter | | `caster_bolts` |
| Mass (kg) | | `masses["caster"]` |

## Razor disc and solar panel (step 1)

| Measurement | Value | `params.py` field |
|---|---|---|
| Disc motor model, driver model | | — |
| Motor can diameter and height (mm), shaft diameter | | `razor_motor_d`, `razor_motor_h` |
| No-load rpm at 36 V, no-load current | | — |
| Cutting power, lawn mown yesterday (W) | | `drive_energy.RAZOR_W` |
| Cutting power, one week's growth (W) | | — (catch-up limit) |
| Spin-down time after power-off (s) | | — (brake needed if > 3 s) |
| Panel: size (mm), Voc, Isc flat at midday, Isc bright overcast | | `panel_size`, `panel_w_peak` |

## Reel mower test (step 1, T1b)

| Measurement | Value | Feeds |
|---|---|---|
| Mower model, cut width, blade count | | — |
| Pull force at 0.6 m/s, strip mown yesterday (N) | | D31 decision |
| Pull force, 3-day strip (N) | | D31 decision |
| Jams per 100 m; uncut stalks per 100 m | | D31 decision |
| Mass whole / stripped to reel + wheels (kg) | | deck mass if chosen |

## Battery and enclosure (step 7)

| Measurement | Value | `params.py` field |
|---|---|---|
| Pack size (mm) and mass | | `battery_size`, `masses["battery"]` |
| Enclosure outside size (mm) | | `ebox_size` |

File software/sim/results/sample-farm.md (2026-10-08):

# SITL results: sample-farm.json

ArduPilot Rover 4.6.3 SITL (rover-skid model), params `software/ardupilot/params`, Lua `blade_interlock.lua`. **4/4 checks passed.**

| Scenario | Check | Result | Detail |
|---|---|---|---|
| mission | mission completes | ✅ | 22065 s sim |
| mission | path tracking while mowing, p95 ≤ 0.15 m | ✅ | p95 0.100 m, median 0.031 m, max 0.281 m |
| mission | actual cut ≥ planned − 2 % | ✅ | actual 97.5%, planned 98.0% |
| mission | blade on only while armed in AUTO | ✅ | 0 violations |

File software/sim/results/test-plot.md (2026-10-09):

# SITL results: test-plot.json

ArduPilot Rover 4.6.3 SITL (rover-skid model, razor deck), params `software/ardupilot/params`, Lua `blade_interlock.lua`. **13/13 checks passed.**

| Scenario | Check | Result | Detail |
|---|---|---|---|
| mission | mission completes | ✅ | 1476 s sim |
| mission | path tracking while mowing, p95 ≤ 0.15 m | ✅ | p95 0.128 m, median 0.040 m, max 0.228 m |
| mission | actual cut ≥ planned − 2 % | ✅ | actual 93.7%, planned 94.1% |
| mission | blade on only while armed in AUTO | ✅ | 0 violations |
| rc_loss | RC loss → Hold and blade off within 2.5 s | ✅ | 1.60 s |
| estop | e-stop → disarmed and blade off within 0.5 s | ✅ | 0.00 s |
| restart | e-stop → disarmed and blade off within 0.5 s | ✅ | 0.10 s |
| restart | after release: stays disarmed and still | ✅ | re-armed=False, moved 0.000 m |
| gps_loss | GPS loss → blade off within 1.0 s | ✅ | 0.20 s |
| gps_loss | GPS loss → paused (Hold) within 3 s, < 2 m travelled | ✅ | after 2.2 s; travelled ≤ 1.45 m (dead-reckoned estimate) |
| gps_loss | GPS back → mission resumes by itself | ✅ | after 3.3 s |
| fence | commanded outside the fence: stays within 1.0 m of it | ✅ | max excursion 0.21 m |
| fence | blade off outside AUTO | ✅ |  |

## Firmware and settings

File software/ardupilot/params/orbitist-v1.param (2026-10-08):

# Orbitist platform v1 - ArduPilot Rover 4.6 baseline parameters
# Load on top of the firmware defaults (Mission Planner: Config > Full Parameter List > Load from file).
# Values marked TUNE are starting points; set them during commissioning and commit the result.
# Every value here is also exercised in simulation (software/sim, run_sitl.py).

# --- Frame: skid steer, one VESC per side ----------------------------------
FRAME_CLASS      1
SERVO1_FUNCTION  73      # throttle left  -> VESC L (through K4 signal relay)
SERVO3_FUNCTION  74      # throttle right -> VESC R
MOT_PWM_TYPE     0
MOT_SAFE_DISARM  1       # no PWM pulses while disarmed -> VESC timeout brake holds the robot

# --- Speeds: v1 mows at 0.6 m/s (the bumper protects up to 0.61 m/s) -------
CRUISE_SPEED     0.6
CRUISE_THROTTLE  30      # TUNE: with VESC 'PID speed' PPM control scaled to ~2 m/s at 100 %
WP_SPEED         0.6
WP_RADIUS        0.2     # SITL: 0.3 cut corners into tree fences, 0.1 made the robot hunt at waypoints
WP_ACCEL         0.5
WP_PIVOT_ANGLE   30      # pivot in place for heading changes above 30 deg
WP_PIVOT_RATE    45      # deg/s while pivoting
ATC_ACCEL_MAX    0.5
ATC_DECEL_MAX    2.0
ATC_STR_RAT_MAX  60      # TUNE
ATC_STR_RAT_FF   0.3     # TUNE: ~1 / (max pivot rate, rad/s) = 1 / (2 x 2 m/s / 1.25 m track)

# --- Arming: switch only, never sticks -----------------------------------------
ARMING_RUDDER    0
RC7_OPTION       153     # ArmDisarm switch on the transmitter
ARMING_REQUIRE   1

# --- Failsafes -----------------------------------------------------------------
FS_ACTION        2       # Hold
FS_TIMEOUT       1.0
FS_THR_ENABLE    1       # RC loss -> FS_ACTION
FS_GCS_ENABLE    0       # v1 supervision is the wireless e-stop + RC; enable once telemetry is reliable
FS_EKF_ACTION    1       # Hold
FS_CRASH_CHECK   2       # stuck or blocked -> Hold and disarm
BATT_MONITOR     4       # analog voltage + current (power module)
BATT_LOW_VOLT    34.0    # 10S Li-ion; 12S LiFePO4 would be ~37.5
BATT_CRT_VOLT    32.5    # 12S LiFePO4: ~36.0
BATT_FS_LOW_ACT  2       # Hold
BATT_FS_CRT_ACT  2       # Hold

# --- Geofence: lawn zones + paths as inclusion polygons, trees/beds excluded --
FENCE_ENABLE     1
FENCE_TYPE       4       # polygon fences only
FENCE_ACTION     2       # Hold
FENCE_MARGIN     0.1
AVOID_ENABLE     2       # proximity sensors only (phase 2). Fence *avoidance* (bit 0) keeps the robot
                         # AVOID_MARGIN from the fence and stalls the perimeter laps; the fence
                         # still enforces a hard stop (FENCE_ACTION) and the planner keeps paths inside.
AVOID_MARGIN     0.5

# --- GPS ---------------------------------------------------------------------
GPS1_TYPE        1       # auto (u-blox ZED-F9P)
GPS_AUTO_CONFIG  1

# --- Blade: relay 1 drives K5, owned by scripts/blade_interlock.lua -------------
RELAY1_FUNCTION  1
RELAY1_PIN       -1      # set at commissioning to the AUX output wired to the K5 relay module
RELAY1_DEFAULT   0       # off at boot
SCR_ENABLE       1       # Lua scripting (copy scripts/ to the SD card APM/scripts/)

# --- Missions: a zone can need ~700 waypoints; store missions on the SD card ---
BRD_SD_MISSION   64      # kB, ~4000 waypoints at 15 bytes each
BRD_SD_FENCE     16      # kB; the internal fence store holds only 84 points (planner stays under 80 anyway)

# Script parameters (appear after the first boot with the script installed, set from the GCS):
#   BLD_MIN_FIX = 6 (RTK fixed), BLD_ESTOP_SRC = 1 (GPIO), BLD_ESTOP_PIN = <ESTOP_OK input>,
#   BLD_TILT_DEG = 25, BLD_RELAY = 0, BLD_MSG_ID = 1, BLD_FIX_PAUSE = 2 (s)

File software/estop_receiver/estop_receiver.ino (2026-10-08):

// Wireless e-stop receiver: fail-safe watchdog between an RC receiver and the e-stop loop relay.
//
// Hardware: Arduino Nano (ATmega328P) or Pro Mini 5 V.
//   D2  <- PWM signal from a dedicated ELRS PWM receiver channel (the "RUN" switch on the transmitter)
//   D7  -> relay module input (active HIGH). The relay's NO contact is in series with the NC e-stop loop.
//   D13 -> onboard LED: solid = RUN, fast blink = stopped (no valid signal), slow blink = stopped (switch off)
//
// The relay is energised ONLY while valid pulses keep arriving AND the RUN switch is high.
// Anything else (transmitter off, out of range, receiver unplugged, broken wire, switch off,
// firmware hang) drops the relay and opens the e-stop loop.
//
// Receiver failsafe must be set to "No Pulses" (ELRS Lua -> Failsafe). This code also rejects
// stale signals on its own, but "No Pulses" makes the failure obvious.

#include <avr/wdt.h>

const uint8_t PIN_PWM = 2;     // INT0
const uint8_t PIN_RELAY = 7;
const uint8_t PIN_LED = 13;

const uint16_t PULSE_MIN_US = 900;    // outside this window = invalid
const uint16_t PULSE_MAX_US = 2100;
const uint16_t RUN_THRESHOLD_US = 1700;  // switch "up" ~2000 us
const uint32_t SIGNAL_TIMEOUT_MS = 100;  // RC frames arrive every ~20 ms; 5 missed frames = stop
const uint8_t RUN_CONFIRM_PULSES = 10;   // require ~0.2 s of steady RUN before closing the relay

volatile uint32_t riseMicros = 0;
volatile uint16_t lastPulseUs = 0;
volatile uint32_t lastPulseMillis = 0;
volatile bool newPulse = false;

void onEdge() {
  uint32_t now = micros();
  if (digitalRead(PIN_PWM)) {
    riseMicros = now;
  } else {
    lastPulseUs = (uint16_t)(now - riseMicros);
    lastPulseMillis = millis();
    newPulse = true;
  }
}

void setup() {
  MCUSR = 0;
  wdt_disable();
  // Relay OFF before anything else: the pin defaults to input (relay off) through reset.
  digitalWrite(PIN_RELAY, LOW);
  pinMode(PIN_RELAY, OUTPUT);
  pinMode(PIN_LED, OUTPUT);
  pinMode(PIN_PWM, INPUT);
  attachInterrupt(digitalPinToInterrupt(PIN_PWM), onEdge, CHANGE);
  wdt_enable(WDTO_250MS);  // a hung loop resets the MCU, which drops the relay
}

void loop() {
  static uint8_t runCount = 0;
  static bool run = false;

  noInterrupts();
  uint16_t pulse = lastPulseUs;
  uint32_t pulseAge = millis() - lastPulseMillis;
  bool fresh = newPulse;
  newPulse = false;
  interrupts();

  bool valid = pulseAge < SIGNAL_TIMEOUT_MS && pulse >= PULSE_MIN_US && pulse <= PULSE_MAX_US;
  bool runRequested = valid && pulse >= RUN_THRESHOLD_US;

  if (!runRequested) {
    runCount = 0;
    run = false;
  } else if (fresh && runCount < RUN_CONFIRM_PULSES) {
    runCount++;
  }
  if (runCount >= RUN_CONFIRM_PULSES) {
    run = true;
  }

  digitalWrite(PIN_RELAY, run ? HIGH : LOW);

  // LED status.
  uint32_t t = millis();
  if (run) {
    digitalWrite(PIN_LED, HIGH);
  } else if (!valid) {
    digitalWrite(PIN_LED, (t / 100) % 2);
  } else {
    digitalWrite(PIN_LED, (t / 500) % 2);
  }

  wdt_reset();
}

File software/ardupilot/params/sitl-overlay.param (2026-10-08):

# Simulation-only overrides, loaded after orbitist-v1.param by software/sim/sitl.py.
# Never load this on the real robot.

RELAY1_PIN       13      # any valid SITL pin, so the relay exists
SIM_GPS_TYPE     1
SIM_GPS_NOISE    0.02    # ~2 cm position noise, like an RTK fix
ARMING_CHECK     1
MOT_SAFE_DISARM  0       # SITL reads "no pulses" as full reverse; neutral models the VESC timeout brake
CRUISE_THROTTLE  15      # SITL skid model: 4 m/s at 100 % throttle
SIM_BATT_VOLTAGE 40.0    # a charged 10S pack
SIM_BATT_CAP_AH  20      # 20 Ah
SIM_GPS_HZ       10      # RTK receiver rate / latency
SIM_GPS_LAG_MS   50
# Steering tuned for the SITL skid model (140 deg/s max turn rate): halves the weave vs defaults.
# The real robot is tuned during commissioning; these numbers don't transfer.
ATC_STR_RAT_FF   0.41
PSC_POS_P        0.5

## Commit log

2026-10-08 Add platform v1 design brainstorm and organize repo
    - Move the Sept 2026 vineyard concept report into docs/concept/
    - Add docs/design/platform-v1.md: single zero-turn rover for autonomous
    mowing, ArduPilot Rover + RTK GNSS, modular belly/hitch/top-deck mounts,
    safety kill chain, sizing math, roadmap, open questions
    - Add decision log, v1 BOM (CSV), and hardware/software READMEs
    [platform-v1-bom.csv]
2026-10-08 Update v1 design with farm site parameters
    - Add site parameters: ~3 acres, Ryobi mower/batteries on hand, cell
    coverage, no RTK service nearby
    - Size coverage for 3 acres; adopt daily-zone mowing from a charging dock
    and move the dock to the front of phase 2
    - Require own RTK base station (OPUS-fixed position, 915 MHz link)
    - Mower module from a second used Ryobi mower sharing existing batteries
    - Choose Onshape for CAD with STEP/DXF/STL exports to the repo
    - Update decision log (D10-D13), BOM, and remaining open questions
    [platform-v1-bom.csv]
2026-10-08 Add licenses, site parameters, twin-deck frame, and ordering plan
    - License: CERN-OHL-W-2.0 (hardware), Apache-2.0 (software),
    CC BY-SA 4.0 (docs) with full texts in LICENSES/ and a plain summary
    - Record flat terrain, open sky, 8 ft paths; size the frame for twin
    decks from day one (D14) and log the license choice (D15)
    - Add a phased ordering plan, starting with GPS + autopilot so the RTK
    base can be surveyed and lawn boundaries mapped before snow
    - Update BOM: second Ryobi deck, RTK correction radio, wider frame
    [platform-v1-bom.csv]
2026-10-08 Add parametric CAD model of the platform v1 frame
    - build123d model (params.py / model.py / build.py) of the frame, hub
    motor drive forks, casters, Ryobi-sized decks, and payload placeholders
    - Single- and twin-deck (staggered, 50 mm cut overlap) configurations
    - Exports: STEP assemblies, renders, drive fork plate DXF, extrusion cut
    list, and a report with mass, CG, axle loads, tongue-weight limit, and
    clearance checks
    - Update design doc envelope with model results
    [drive-fork-side-plate.dxf, platform-v1-single.step, platform-v1-twin.step]
2026-10-08 Add strength check for drive forks and frame; apply fixes
    - strength.py: hand calcs for fork plates, dropout bearing, torque
    reaction, fork-to-rail joint, cross members, side rails, and hitch,
    with explicit load cases -> exports/strength-report.md
    - Fixes from the check: torque arms (required), saddle-mounted drive
    forks, 30x60 cross member at x=215, gussets at drive-adjacent joints;
    no towing until an A-frame drawbar is added
    - New DXFs: torque arm and frame gusset; cut list, BOM, ordering plan,
    design doc, and decision log (D16) updated
    [frame-gusset.dxf, platform-v1-bom.csv, platform-v1-single.step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]
2026-10-08 Record code-based CAD as the source of truth (revise D13)
2026-10-08 Add e-stop/wiring design, RTK base station guide, casters and bumper
    - hardware/electrical: power distribution, Category 1 e-stop chain
    (signal cut -> VESC brake -> contactor after 1 s), signal wiring,
    58 V-rated fusing, safety-critical settings, commissioning tests
    - software/estop_receiver: fail-safe wireless e-stop watchdog firmware
    (Arduino Nano, compiles with arduino-cli)
    - docs/guides/rtk-base-station.md + software/base-station script to
    configure a ZED-F9P base (raw log, survey-in, fixed) without u-center
    - CAD: plate-mount casters on steel corner plates (new DXF), sliding
    front bumper with foam, frame raised to 320 mm, 30x60 front member
    - Strength: caster plate checks and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
    [caster-plate.dxf, frame-gusset.dxf, platform-v1-bom.csv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]
2026-10-08 Sync ordering plan with current extrusion cut list
2026-10-08 Refine design and add simulation: planner, SITL tests, autopilot config
    Design refinements
    - v1 deck moves to the twin layout's rear-right slot (cuts within ~19 cm
    of obstacles on the right; twin upgrade only adds a deck)
    - drive_energy.py: hub-motor operating points and daily energy budget;
    flags motor heating (worst case) and blade power as the key unknowns
    - Confidence plan with de-risking tests T1-T4 before the main purchase;
    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
    [caster-plate.dxf, drive-fork-side-plate.dxf, frame-gusset.dxf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]
2026-10-08 Add full-size zone SITL result: 97.5% cut, time within 1% of plan
2026-10-09 Detailed CAD: real T-slot frame, bolted joints, motors, casters, decks, payload
    - Split the model into parts/ (common, plates, frame, drive, casters,
    deck, payload); model.py assembles and re-exports the analysis helpers
    - Frame: 30-series slot-8 profiles, cast corner brackets, top-face
    gussets, battery support rails, bolts at every joint
    - Drive: treaded tires, rims, motor cans, flatted axles with shoulders,
    forks extruded from the DXF outline with saddle tabs, torque arms,
    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
    [caster-plate.dxf, drive-fork-side-plate.dxf, frame-gusset.dxf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]
2026-10-09 Add first-principles form-factor exploration; D26 pause on deck/battery decision
2026-10-09 Razor-disc deck and solar roof become the v1 baseline (D27-D30)
    - CAD: parts/razor_deck.py (four Ø280 razor discs, plate cut to the caster
    swivel circle, skirt, rollers, hangers) and parts/roof.py (posts, roof
    frame, two panels, MPPT, antenna + e-stop on the roof); new "razor"
    config is the default; razor-disc.dxf; close-ups of deck and roof
    - Renderer draws parts as spatial patches so depth sorting works
    - Energy model: per-config blade power and a solar balance; razor + roof
    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
    [caster-plate.dxf, drive-fork-side-plate.dxf, frame-gusset.dxf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]
2026-10-09 D31: evaluate a ground-driven reel gang against the razor discs (T1b field test)
